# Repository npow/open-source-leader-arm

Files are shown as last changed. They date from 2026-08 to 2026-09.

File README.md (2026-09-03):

# Open-source Leader Arm

Open-source, low-cost, 3D-printed leader arm for teleoperating an SO-ARM

> **YAM prototype:** The `yam-encoder-leader` branch includes a no-solder,
> eight-piece, bearing-supported potentiometer leader for the six-axis I2RT
> YAM. A recorded two-leader cart was $32.34 before tax and import charges. See the
> [complete linked BOM, print list, assembly order, and validation limits](yam/README.md).

https://github.com/user-attachments/assets/977a0b56-c7d2-4a90-b86a-445dd3963871

A leader arm is moved by an operator to teleoperate a follower robot arm. A leader arm's joints are never driven, they simply report their joint angles, which the follower mirrors. So instead of using expensive servos, a cheap magnetic encoder like the AS5600 can be used. It results in an arm which is lighter to move by hand and is much cheaper than the one built with servos. 

Currently, the leader arm is tested against a simulated SO-ARM in MuJoCo with live physics, so you can pick up and move objects in the scene without a physical follower arm.

## Bill of materials

|Component| Quantity | Price|
|-|-|-|
|AS5600 encoder + Diametric magnet | 6 | 6 x 186 INR = 1,116 INR (~11.7 USD)|
|608 Bearing | 6 | 6 x 30 INR = 180 INR (~1.9 USD)|
| CJMCU TCA9548A I2C 8 Channel Multiplexer| 1 | 59 INR (~0.6 USD)|
|ESP32 | 1 | 550 INR (~5.8 USD)|
|28 AWG Silicon Wires | ~5m per color (4 colors) | 477 INR (~ 5 USD)|
|M3x10mm screws | 60 | 195 INR (~2 USD)|
|7x9cm Perfboard | 1 | 42 INR (~0.45 USD)|
| Rubber band | 1 | Negligible|
| |Total | 2,619 INR (~27.45 USD)|

Excluding the price of the 3D printed parts.

For context: the STS3215 servo used in the standard LeRobot leader arm costs around 24 USD each, and the leader arm needs six, roughly 144 USD in servos alone. Our entire component list comes in under 28 USD.

## How it works?
How it works explainer

**Why a mux?** - The AS5600 encoder has a fixed I2C address (0x36) and can't be changed. So we can't put more than one on a bus as they will all share the same address. The TCA9548A mux gives each encoder its own separate channel and connects one channel to the ESP32 at a time, so all six encoders can be read without any collision. 

## Wiring
wiring diagram

| TCA9548A | ESP32 | 
| --- | --- |
| VIN | 3V3 |
| GND | GND |
| SDA | D18 |
| SCL | D19 |
| RST | 3V3 |
| A0, A1, A2 | GND |

| AS5600 | ESP32 |
| --- | --- |
| VCC | 3V3 |
| GND, DIR | GND |

| AS5600 | TCA9548A |
|---|---|
| SDA | SDn |
| SCL | SCn |

n = the channel for that joint \
joint 0 → SD0/SC0, ... joint 5 → SD5/SC5

## Print Settings

Printed in PLA, 0.2mm layer height and 15% infill.

There are 19 unique parts and a total of 47 parts. All the parts are designed to not need support while printing. All the parts are already oriented for printing; if any part loads at an odd angle, lay its flat face on the bed. 

## Firmware

Flash firmware.ino to the ESP32 using the Arduino IDE: 

1. Install the ESP32 board support (Tools → Board → Boards Manager → search "esp32")
2. Open 'firmware/firmware.ino' and select your ESP32 board and port, and upload.
3. After uploading, open the serial monitor at **115200 baud rate** to check the output.

The firmware uses only the built-in 'Wire' library, so there's nothing else to install.

On boot it prints a channel scan. It prints "-1" if there is an issue with the connection, missing magnet or miswired encoder etc.,

If everything works then it prints "magnet ok"

Example : # ch0: AS5600 found, magnet ok, raw 1234

After the scan, it streams the six encoder readings as a comma-separated line, at 100 Hz.

## Running the software

The python side reads the encoder stream and drives a simulated SO-ARM in MuJoCo.

Install the dependencies and clone the robot model (the scripts expect it in the working directory)

```bash
pip install "mujoco>=3.2" pyserial
git clone https://github.com/google-deepmind/mujoco_menagerie.git
```

Then run one of the two scripts, passing your ESP32's port:

```bash
python teleop.py --port COM3              # plain teleop, empty scene
python teleop_sort_task.py --port COM3    # teleop + block sorting
```

On Linux, the port looks like '/dev/ttyUSB0'.

The script opens the simulated follower arm in its natural rest pose (hardcoded as the reference pose), so when the script starts, hold the leader arm in its reference pose and press ENTER. This makes sure that both the leader and the follower arm start with the same pose.

## Acknowledgements

This project builds on the work of several open-source projects:

- [SO-ARM100](https://github.com/TheRobotStudio/SO-ARM100) - the follower arm design this leader is built to teleoperate.
- [LeRobot](https://github.com/huggingface/lerobot) - the leader/follower teleoperation approach this project is based on.
- [MuJoCo Menagerie](https://github.com/google-deepmind/mujoco_menagerie) - the SO-ARM simulation model used by the teleop scripts.

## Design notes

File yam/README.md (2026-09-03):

# Simple no-solder YAM leader

A passive seven-axis potentiometer controller for the I2RT YAM. Each leader uses
seven factory-wired B10K rotary potentiometers, seven 6000-2RS bearings, an
Arduino Nano with soldered headers, a Nano I/O shield, and eight printed PETG
parts. The shopping list covers two leaders.

This is a first-print prototype, not qualified hardware. The tests check nominal
CAD geometry, motion sweeps, and a cable-length model. They do not prove printer
fit, strength, or a collision-free workspace. Print and pull-test the coupon
before committing to a full arm.

## A YAM at 0.68 scale

Teleoperation here is joint-space: each leader angle goes straight to the
matching follower joint. Your hand tracks the follower's gripper only if every
segment carries the same scale factor, so the chain is generated from
[`yam.urdf`](https://github.com/i2rt-robotics/i2rt/blob/main/i2rt/robot_models/arm/yam/v1/yam.urdf)
instead of being drawn to fit a print bed.

| Segment | YAM | Leader |
| --- | ---: | ---: |
| Base to J1 | 68.0 mm | 46.2 mm |
| J1 to J2 (shoulder offset) | 60.2 mm | 40.9 mm |
| J2 to J3 (upper arm) | 272.8 mm | 185.5 mm |
| J3 to J4 (forearm) | 261.5 mm | 177.8 mm |
| J4 to J5 | 90.9 mm | 61.8 mm |
| J5 to J6 | 53.9 mm | 36.7 mm |

The follower's lateral shoulder and elbow offsets are reproduced, so the forearm
folds past the upper arm the way the real arm's does. Assembled, the leader
reaches 321 mm forward and stands 326 mm tall.

It will not go much smaller. A GELLO joint is a 24 mm servo; a joint here is a
26 mm bearing plus a 17 mm potentiometer needing 35 mm of shaft and cradle behind
it. YAM's J5-to-J6 offset is 53.9 mm, or 36.7 mm at this scale, and the wrist
fits only because J5's sensor faces away from it and link 5 reaches J6's bearing
from behind. Below 0.66 the folded forearm hits the base plate. Smaller needs a
9 mm pot on a smaller bearing, or AS5600 encoders.

Two dimensions are not scaled, neither of them a mapped joint: the gripper lever
pivots 72 mm from the wrist roll axis because J6's potentiometer occupies the
first 35 mm of that direction, and the base plate, pedestal, and controller tray
are sized for the parts they hold.

`LEADER_SCALE` in `simple_cad/build_simple_leader.py` sets the size, and
`test_leader_is_a_uniformly_scaled_yam` fails if any segment drifts off it.

## Buy this for two leaders

Put the stated quantity in the cart. Quantities cover both leaders together.
Prices and links checked September 3, 2026.

| Buy this item | Cart quantity | Select exactly this option |
| --- | ---: | --- |
| [TZT WH148 factory-wired potentiometer](https://www.alibaba.com/product-detail/TZT-WH148-Potentiometer-B10K-B100K-Speed_1600768301952.html) | **14** | `B10K`, linear taper, 15 mm shaft, XH2.54 three-pin lead |
| [6000-2RS bearing](https://www.alibaba.com/product-detail/10x26x8-mm-ABEC-7-6000-2rs_1600053563089.html) | **20** | `10×26×8 mm`, sealed `6000-2RS`; fourteen used, six spare |
| [TZT ATmega328P/CH340 Nano V3.0](https://www.alibaba.com/product-detail/TZT-Type-C-USB-Nano-3_1600566932166.html) | **2** | `328P-Welded-TYPE-C USB`; both long header rows already soldered |
| [TZT Nano I/O sensor shield](https://www.alibaba.com/product-detail/TZT-NANO-V3-0-Adapter-Prototype_1601021706384.html) | **2** | Assembled red 58×54 mm board, two Nano socket rows, S/V/G headers |
| [30 cm male-to-female Dupont ribbon, 40 wires](https://www.alibaba.com/product-detail/30cm-40pin-M-to-F-Color_1601699032813.html) | **3** | `30cm`, `M to F`, `40P` |

Three ribbons, because a `40P` ribbon is forty separate one-conductor jumpers
joined side by side, not forty three-wire cables. One leader uses 13 three-wire
segments, or 39 wires, so two leaders use 78. Two ribbons give 80, which covers
that only if the delivered pigtails are 176 mm or longer, and the listing does
not state the length. At 160 mm the arm needs 84. Three ribbons give 120 and
cover leads down to 100 mm.

Expect roughly $33 before tax and import charges: about $18 of items and $26 of
shipping, less roughly $12 in discounts. With
[8.625% San Francisco sales tax](https://www.cdtfa.ca.gov/taxes-and-fees/rates.aspx)
that is about $36. Alibaba shows the exact shipping discount and import charge
only at checkout, so use the final charged total.

Also have a 1 kg spool of PETG, two USB-C data cables, and either eight #8 (about
4 mm) wood screws or two table clamps. Keep cable ties or electrical tape for
strain relief. Solid volume is 313 cm³ per leader, so slice the plate before
ordering only one spool.

## Print

Download this branch as a [ZIP](https://github.com/npow/open-source-leader-arm/archive/refs/heads/yam-encoder-leader.zip)
and use only `yam/simple_cad/generated/stl`. Do not use `cad_files/stl`; those
belong to the upstream SO-ARM design.

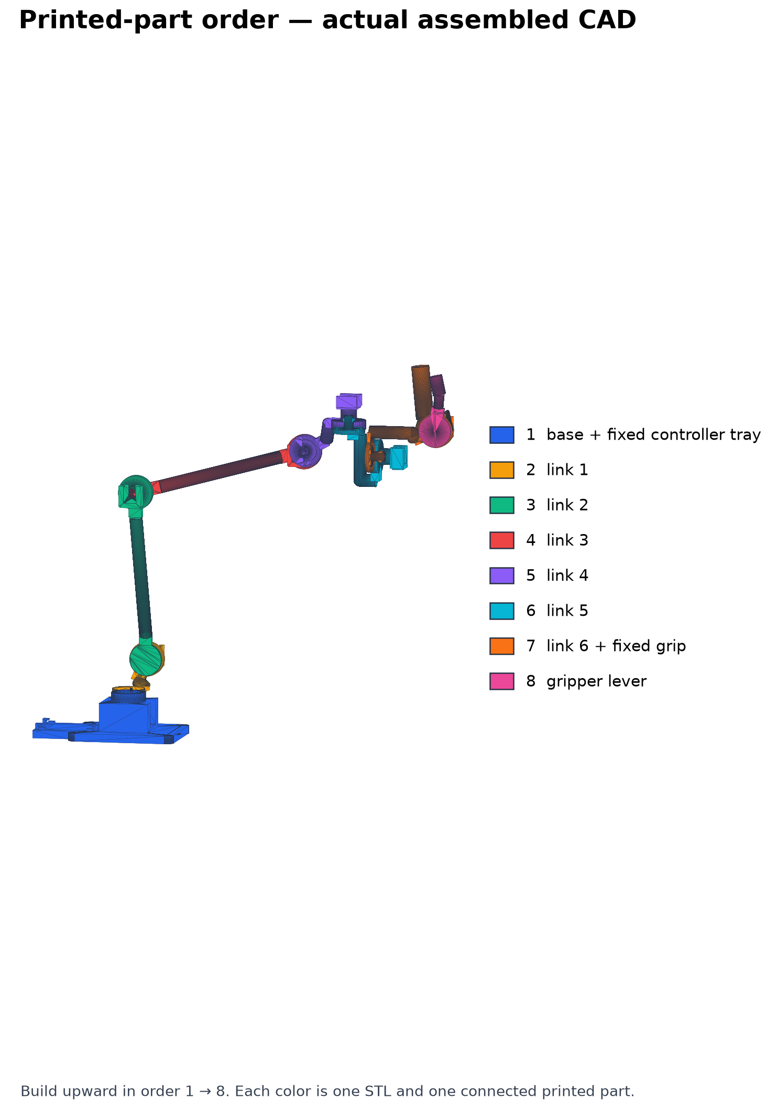
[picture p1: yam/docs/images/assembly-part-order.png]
The eight printed parts in assembly order


Print one [`joint_fit_test.stl`](simple_cad/generated/stl/joint_fit_test.stl)
first. It is a disposable coupon for the bearing pocket, snap axle, split shaft
socket, and pot cradle. Seat a bearing, snap the two pieces together, install a
pot, and pull firmly. Both snap shoulders must stay behind the bearing's inner
race and the printed wall must not crack.

One leader uses one copy of each file. Print two copies of every file for two
leaders:

1. [`simple_base.stl`](simple_cad/generated/stl/simple_base.stl), including the fixed controller tray
2. [`simple_link_1.stl`](simple_cad/generated/stl/simple_link_1.stl)
3. [`simple_link_2.stl`](simple_cad/generated/stl/simple_link_2.stl)
4. [`simple_link_3.stl`](simple_cad/generated/stl/simple_link_3.stl)
5. [`simple_link_4.stl`](simple_cad/generated/stl/simple_link_4.stl)
6. [`simple_link_5.stl`](simple_cad/generated/stl/simple_link_5.stl)
7. [`simple_link_6.stl`](simple_cad/generated/stl/simple_link_6.stl), including the fixed gripper jaw
8. [`simple_gripper_lever.stl`](simple_cad/generated/stl/simple_gripper_lever.stl)

PETG, 0.20 mm layers, five walls, six top/bottom layers, 25% gyroid. Enable
organic or tree supports from the build plate where needed, and about 0.20 mm
elephant-foot compensation. **Do not scale the STL.** The proportions are what
make the arm steer like the follower, and a scaled axle will not carry load. If
the coupon fit is wrong, tune the clearances in
[`simple_cad/README.md`](simple_cad/README.md) and regenerate.

Check your bed against the long parts:

| Part | Footprint as exported |
| --- | --- |
| `simple_link_2` (upper arm) | 35 × 214 mm |
| `simple_link_3` (forearm) | 201 × 75 mm |
| `simple_base` | 149 × 90 mm |

Everything else is under 110 mm. A 220 mm bed takes every part square on; a
180 mm bed takes the two long links only on the diagonal. `simple_link_2` exports
standing 95 mm tall on a 35 mm footprint, so it slices into a lot of support.
Re-orient it if you prefer, but keep the joint faces off the bed.

Editable STEP files are in `simple_cad/generated/step`.

## Assemble one leader

Repeat for the second leader.

### 1. Join the eight printed parts

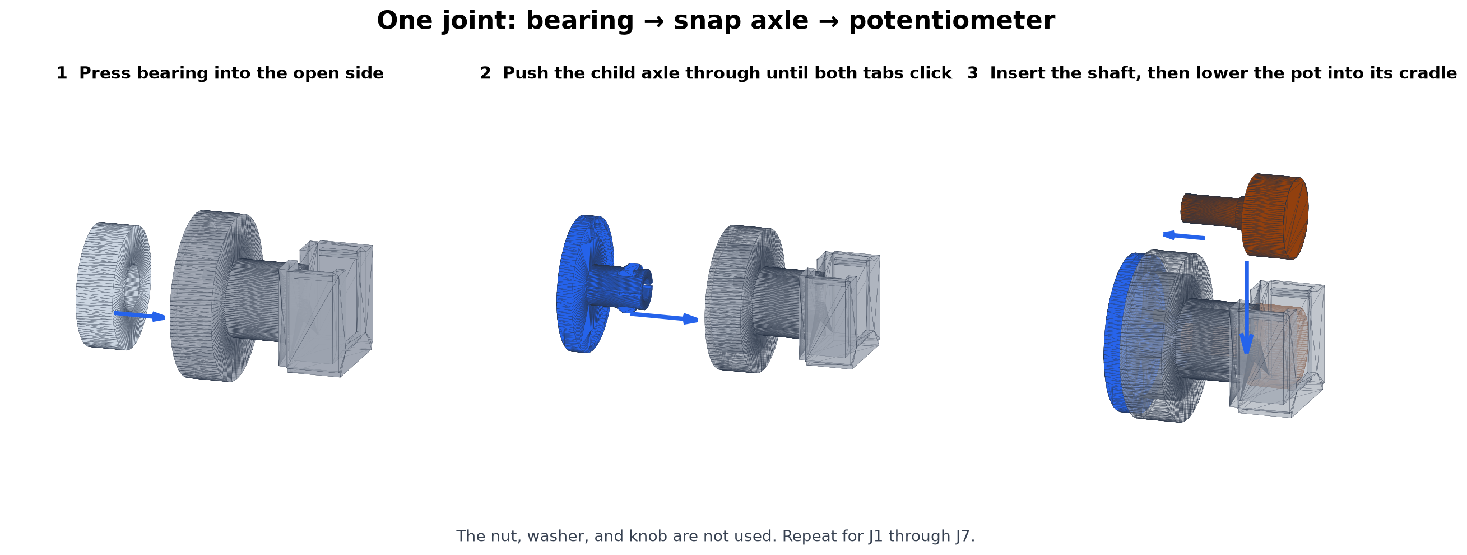
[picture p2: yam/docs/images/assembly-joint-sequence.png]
How a bearing, child axle, and potentiometer form one joint


1. Press one 6000-2RS bearing fully into the open round socket on the base and on
   links 1 through 6. Push only on the bearing's outer metal race.
2. Push link 1's axle straight through the base bearing until both printed
   shoulders click behind the inner race.
3. Continue in order: base, link 1, link 2, link 3, link 4, link 5, link 6,
   gripper lever.
4. Check that every joint turns freely and that pulling a child away from its
   bearing does not release the snap shoulders.

The bearing and printed flange carry the load. The potentiometer measures the
angle; it is not the axle. No screws or glue belong in a joint.

### 2. Center and install the seven pots

The printed stops are asymmetric, because each one is the follower joint's own
limit seen from the build pose. Center each pot on the middle of its printed
travel, then set the host offsets from
[the table below](#run-the-follower-software).

One joint at a time:

1. Swing the joint gently to each stop and leave it halfway between. Leave the
   gripper fully open for its zero position.
2. Connect the loose pot to the electronics and turn its shaft until the raw
   reading is about `512`.
3. **Unplug USB.** Push the shaft into the split socket, then lower the pot body
   and threaded bushing into the U-shaped cradle.
4. Do not install the pot's nut, washer, or knob.
5. Reconnect USB and move that joint slowly to both stops. The raw reading should
   stay between about `20` and `1000`, and the pot body must not twist.

### 3. Install the Nano shield and Nano

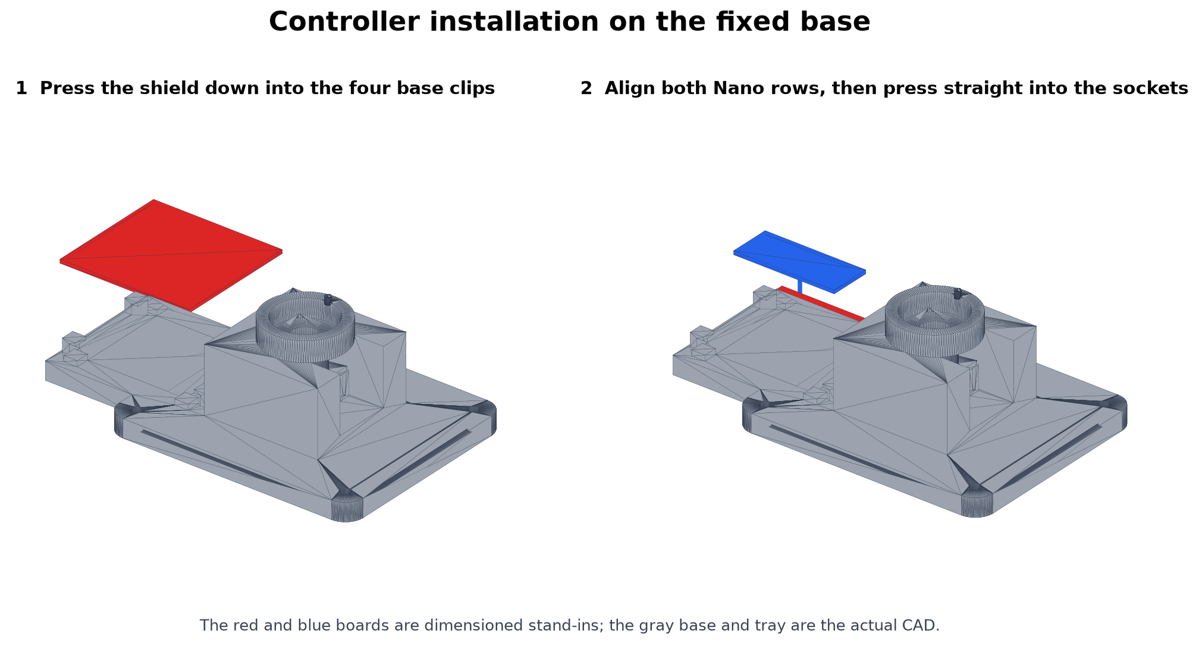
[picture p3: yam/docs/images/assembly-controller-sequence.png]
How the shield and Nano fit the fixed tray on the base


1. Rotate the red 58×54 mm shield so the Nano's USB connector faces outward, away
   from the J1 pedestal, then press it flat into the four clips on the base.
2. Match the labels on the Nano to the labels beside the shield sockets, `VIN` to
   `VIN` and `GND` to `GND`. USB-connector direction alone is not reliable.
3. Check every pin is over a socket, with no one-pin or one-row offset, then
   press both header rows down evenly. A shifted or reversed Nano can be
   destroyed when powered.

### 4. Secure the base

Clamp the base to the table, or use its four mounting holes and four #8 (about
4 mm) wood screws. Secure it before moving the arm through its range.

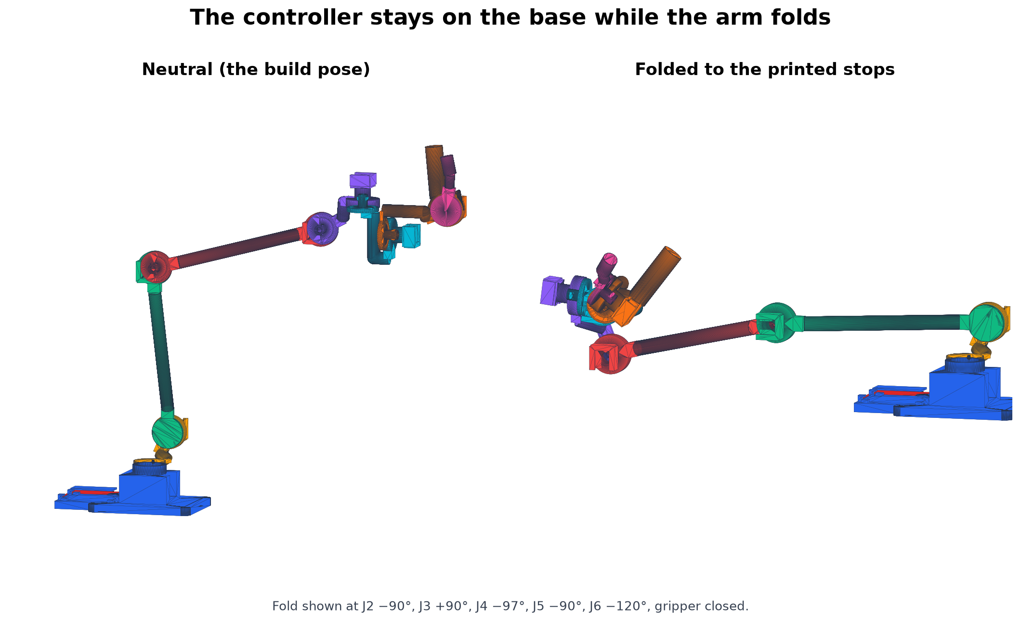
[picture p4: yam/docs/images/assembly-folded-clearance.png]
Neutral and fully folded poses with the controller fixed on the base


Before routing wires permanently, move slowly into the pictured fold, which puts
five joints on their stops at once: J2 −90°, J3 +90°, J4 −97°, J5 −90°, J6 −120°,
gripper closed. Stop rather than force the arm if a part, board, or cable
catches.

One combination is out of bounds. With the shoulder past J2 +20°, keep the elbow
above J3 −60° or the wrist comes down onto the base plate. A printed stop limits
one joint at a time, so this pair is an operating limit rather than a hardware
one.

The snap axles are serviceable but not meant for repeated disassembly. To remove
one, take out the pot, squeeze both axle shoulders inward through the cradle
opening, support the bearing, and pull the child straight out.

## Wire one leader

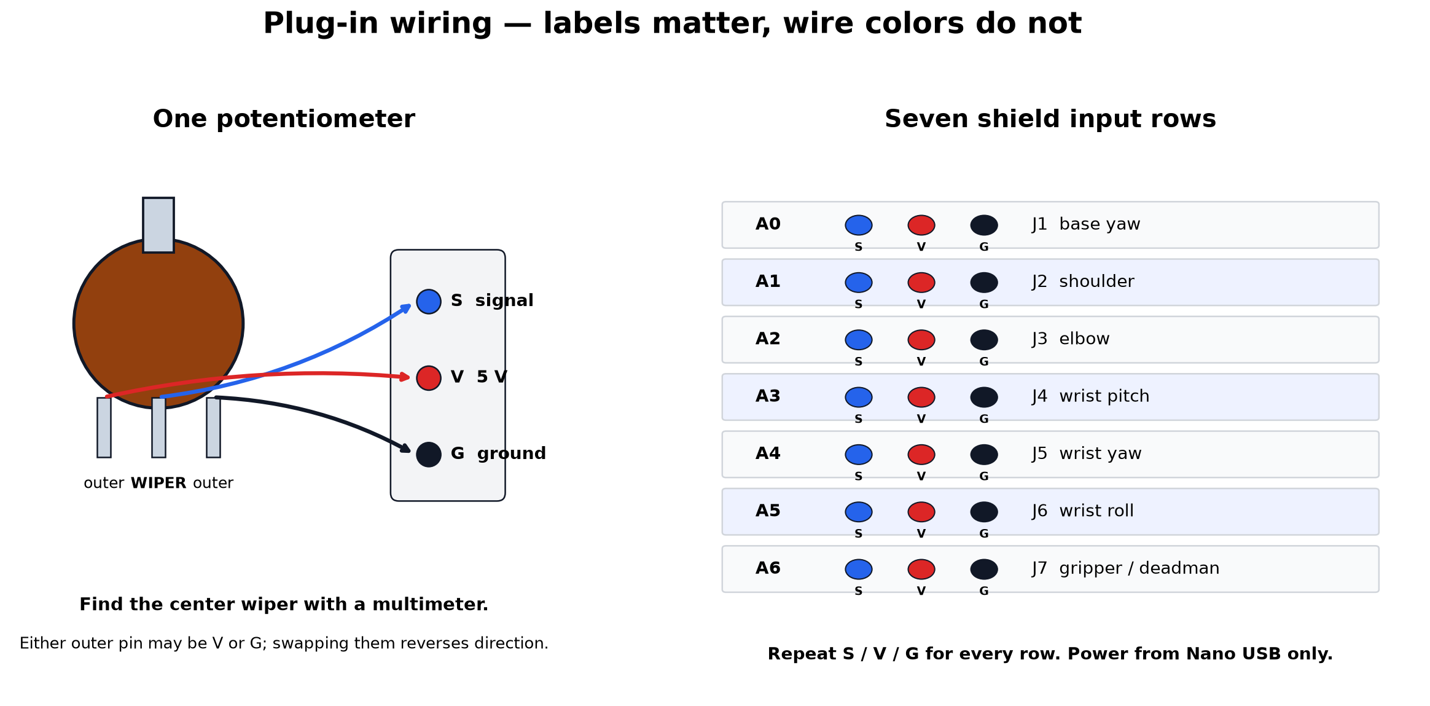
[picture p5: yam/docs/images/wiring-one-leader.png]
Potentiometer S/V/G wiring and the seven Nano-shield inputs


| Shield | Joint |
| ---: | --- |
| A0 | J1 base yaw |
| A1 | J2 shoulder |
| A2 | J3 elbow |
| A3 | J4 wrist pitch |
| A4 | J5 wrist yaw |
| A5 | J6 wrist roll |
| A6 | Gripper/deadman |

### Check every three-wire connector before power

Marketplace wire colors and pin order are not trustworthy. With the pot unpowered
and disconnected, meter its pins: the two outer terminals stay near 10 kΩ apart,
while the center wiper to either outer terminal changes as the shaft turns.
Connect:

- wiper to `S` (signal)
- either outer terminal to `V` (5 V)
- the other outer terminal to `G` (ground)

Swapping the two outer wires only reverses direction. Putting 5 V or ground on
the wiper is wrong. Confirm the XH-style plug or male jumper pins make firm
contact, and never force a housing that does not mate.

Power the Nano and the seven low-current pots from USB only. Do not connect the
shield's barrel jack or an external servo supply.

### Jumper wires per leader

The seller does not specify the factory lead length. The CAD assumes 200 mm, so
measure the delivered pots. At 200 mm, one leader needs:

| Channel | Segments | Wires |
| --- | ---: | ---: |
| J1 | 0 (reaches directly) | 0 |
| J2 | 1 | 3 |
| J3 | 1 | 3 |
| J4 | 2 | 6 |
| J5 | 3 | 9 |
| J6 | 3 | 9 |
| J7 | 3 | 9 |
| Total | 13 | 39 |

A segment is three loose jumpers, one each for S, V, and G, not a three-wire
cable. Peel groups of three off the ribbon and join male to female where a
channel needs more than one. Two leaders use 78 of the 120 wires in three
ribbons.

Leave a loose loop at every moving joint; a taut wire acts like a spring and
distorts the reading. Put junctions on straight link sections, not inside a
bending loop, and secure each one so normal motion cannot pull it apart.

<details>
<summary>CAD cable-length calculation</summary>

| Channel | Centerline route | Moving joints crossed | Total lead needed | 30 cm segments at 200 mm |
| --- | ---: | ---: | ---: | ---: |
| J1 | 61 mm | 0 | 96 mm | 0 |
| J2 | 137 mm | 1 | 226 mm | 1 |
| J3 | 308 mm | 2 | 475 mm | 1 |
| J4 | 468 mm | 3 | 710 mm | 2 |
| J5 | 558 mm | 4 | 857 mm | 3 |
| J6 | 601 mm | 5 | 946 mm | 3 |
| J7 | 653 mm | 6 | 1046 mm | 3 |

The route follows each intervening joint rather than cutting through space, then
adds 25% routing allowance, a 35 mm service loop per moving joint crossed, and
20 mm for connectors and strain relief.

</details>

## Flash and test the controller

Upload
[`firmware/yam_encoder_leader/yam_encoder_leader.ino`](../firmware/yam_encoder_leader/yam_encoder_leader.ino)
in the Arduino IDE:

1. Select Arduino Nano, the correct port, and ATmega328P. If a clone will not
   upload, try ATmega328P (Old Bootloader).
2. Keep the gripper fully released while plugging in USB or resetting. The
   firmware averages that position as the deadman-off baseline.
3. Open Serial Monitor at 115200 baud. It should emit `YAMP1` frames at 100 Hz,
   every raw channel within `[4, 1019]`.
4. Move one joint at a time, confirm the expected channel changes smoothly, then
   pull lightly on its cable and recheck.

The firmware averages four ADC reads per sample. A reading at an ADC endpoint
disables the deadman, but that is a limited wiring check, since an open analog
input can float to a valid-looking value. Squeezing the gripper by about 25
counts sets the protocol's deadman bit. In the hardware host configuration,
releasing it holds the follower at its current measured pose; the simulation
configuration ignores it by default. This is not a safety-rated emergency stop.

## Run the follower software

Use the matching `yam-encoder-leader` branch of
[`npow/gello_software`](https://github.com/npow/gello_software/tree/yam-encoder-leader).
Edit the Nano port in `configs/yam_encoder_sim.yaml`, hold the arm in its neutral
pose with the gripper open, and test one leader in simulation first:

```bash
python experiments/launch_yaml.py \
  --left-config-path configs/yam_encoder_sim.yaml
```

**Those configs do not match this arm out of the box, and this branch does not
change them.** Set each joint's offset so a centered pot reads the follower angle
below, and set `joint_signs` to −1 where shown:

| Joint | Follower angle at a centered pot | `joint_signs` |
| --- | ---: | ---: |
| J1 base yaw | 0° | −1 |
| J2 shoulder | 105° | +1 |
| J3 elbow | 98° | +1 |
| J4 wrist pitch | −3.5° | +1 |
| J5 wrist yaw | 0° | −1 |
| J6 wrist roll | 0° | +1 |

J1 and J5 take −1 because their potentiometers face the other way, which gives
the pedestal and the wrist their clearance. Every axis is one degree of leader
per degree of follower, with no per-joint gain. If a joint still moves backward,
fix it in `joint_signs`; do not swap wires while powered. Use
`configs/yam_encoder_hw.yaml` only after directions, limits, disconnect behavior,
rate limits, and the gripper deadman all work in simulation.

For two leaders, copy the config for the right side with the second Nano's serial
port and the right follower's robot or CAN endpoint, then add
`--right-config-path`. Never point both sides at the same device.

### What the leader cannot reach

Every printed stop is the follower joint's own limit, with two exceptions:

| Joint | Follower travel | Leader travel | Given up |
| --- | --- | --- | --- |
| J1 base yaw | −150° to +180° | ±140° | 40° one way, 10° the other |
| J3 elbow | 0° to 180° | 16° to 180° | 16° at the folded end |

J1 needs 330°, more than one 300° potentiometer can measure, so its stops sit
symmetrically inside what the pot reads. J3 stops short because the printed
forearm, fatter than the real arm's, reaches the upper arm over the last 16° of
its fold.

## Known prototype limitations

- Print and pull-test the coupon. FDM fit and snap strength vary by printer,
  PETG, cooling, and layer adhesion. This design has no certified load rating.
- Every joint clears its full printed-stop range with the whole distal chain
  attached, and the shoulder and elbow are swept as a grid. That does not prove
  every multi-joint combination is free of self-collision, so move slowly and
  never force a fold.
- A faithfully scaled YAM inherits the follower's own folded self-collisions. A
  URDF joint limit is not a promise of a collision-free workspace, on either arm.
- Collision tests use a conservative 78×74×22 mm envelope for the shield, Nano,
  headers, and plugs. Real parts and flexible wire paths still need physical
  inspection.
- WH148 carbon potentiometers are inexpensive wear parts, not precision encoders.
  Verify linearity, backlash, electrical travel, and connector grip.
- This is prototype hand-input equipment, not a payload support or a safety-rated
  control device.

CAD source, regeneration instructions, and geometry tests are in
[`simple_cad`](simple_cad/README.md).

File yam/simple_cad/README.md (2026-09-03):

# Parametric simple YAM leader CAD

[`build_simple_leader.py`](build_simple_leader.py) is the source of truth for
the eight-piece, bearing-supported potentiometer leader. Dimensions are
millimetres. Generated editable STEP and print-oriented STL files are under
[`generated`](generated).

## The chain comes from the follower

`YAM_URDF_CHAIN` holds the joint origins, axes, and limits copied out of
`i2rt/robot_models/arm/yam/v1/yam.urdf`. `yam_chain()` runs forward kinematics
over those rows at `YAM_BUILD_POSE_DEG` and multiplies by `LEADER_SCALE`, which
is the single number that sets the arm's size. `JOINTS` and `JOINT_LIMITS_DEG`
are derived from that and must not be hand-edited.

Joint-space teleoperation only tracks the follower if the leader is a *uniform*
scaling of it, so `test_leader_is_a_uniformly_scaled_yam` compares every segment
against the URDF at both 1.0 and `LEADER_SCALE`. Per-segment adjustment is the
failure this guards against: it leaves every angle legal and silently removes
the correspondence the operator steers by.

`YAM_BUILD_POSE_DEG` uses multiples of 90 degrees so every axis lands on a world
axis, which is all `_orient_x` can build, and it sits near the middle of every
follower joint range. Printed stops then follow as `follower limit - build
angle`, clipped by `POT_USABLE_TRAVEL_DEG` and `SELF_COLLISION_LIMIT_DEG`.
`follower_travel_lost_deg()` reports everything the leader gives up.

`POT_MOUNT_SIGN` flips J1, J5, and J7. The socket and its potentiometer always
extend along +axis, so the sign picks which side of a joint the sensor sticks
out of, and each flip costs a `joint_signs` of −1 in the host config. J1 faces
down so its pedestal is a column under the socket instead of a wedge threaded
through link 1's sweep; J5 faces up so link 5 has a corridor down to J6.

### How small can it go?

What this suite reports at other scales:

| Scale | Result |
| ---: | --- |
| 0.75 | passes |
| 0.70 | collisions all clear, but `simple_link_5` is not a valid single solid |
| 0.68 | passes; shipped |
| 0.67 | passes |
| 0.66 | the folded forearm reaches the base plate |

0.66 is the first real collision, so 0.68 keeps a step of margin. Below that the
base plate and Nano shield stop shrinking with the arm, and then the joints
themselves run out of room.

The model is not valid at every scale in between. `simple_link_5` fails the
valid-solid check at 0.70 and 0.74 while passing at 0.68 and 0.75. The cause is
near-tangency rather than packing: at those spacings the descent beam leaves J5
on a short radial neck that puts its surface about a millimetre from the snap
axle and straddling `STOP_GROOVE_OUTER_RADIUS`, so the union drops a segment
instead of fusing it. If you change `LEADER_SCALE`, run the suite. If link 5
fails, route it out of J5 along the joint axis first, where nothing is nearby,
instead of on that neck.

## Generate and test

```bash
python -m venv .venv-cad
. .venv-cad/bin/activate
pip install -r yam/simple_cad/requirements.txt
python yam/simple_cad/build_simple_leader.py
python yam/simple_cad/render_assembly_guides.py
PYTHONPATH=yam/simple_cad pytest -q yam/simple_cad/test_simple_leader.py
```

The renderer creates the five README figures in `yam/docs/images` from the
same printed-part geometry. Purchased bearings, pots, and boards are shown as
dimensioned stand-ins rather than scanned manufacturer models.

Generation refuses to export unless all eight final parts are connected valid
solids, adjacent rigid parts do not interfere in the assembly zero pose, and
every potentiometer channel fits the documented cable budget.

The test suite moves each joint individually across its complete printed-stop
travel with the entire distal chain attached. It checks every pair of the eight
parts rather than only neighbours, and it includes the fixed controller's
78×74×22 mm electronics envelope.

Additional regressions cover all 27 nominal J4/J5/J6 corner combinations,
shoulder folds across five J1 yaw samples, a wrist-over-tray pose, a six-joint
fold onto the printed stops across the yaw range, and a shoulder/elbow grid that
checks the fold envelope in both directions: everything inside it clears, and the
corner it excludes does collide. They do not exhaustively sample continuous
multi-joint space or prove a self-collision-free workspace.

The gripper's leaf/post overlap is excluded from the pair checks and tested on
its own, because that overlap is the intended elastic spring engagement.

These checks do not replace a physical fit test. FDM holes and snap features
vary with printer, material, layer direction, cooling, and marketplace parts.

## Printer fit constants

Print [`generated/stl/joint_fit_test.stl`](generated/stl/joint_fit_test.stl)
before the full arm. Tune only the compensated values below; do not change the
purchased-component dimensions or scale the STL in a slicer.

| Constant | Default | Meaning |
| --- | ---: | --- |
| `BEARING_POCKET_DIAMETER` | 26.20 | Modeled hole for the 26 mm 6000-2RS outer race |
| `BEARING_POCKET_DEPTH` | 8.15 | Modeled depth for the 8 mm bearing |
| `AXLE_DIAMETER` | 9.80 | Running fit in the 10 mm inner race |
| `POT_BODY_CLEARANCE` | 0.45 | Added diameter around the nominal 17 mm WH148 body |
| `POT_BUSHING_CLEARANCE` | 0.35 | Added diameter around the nominal 7 mm threaded bushing |
| `POT_SHAFT_SOCKET_DIAMETER` | 5.85 | Interference fit inside the nominal 6 mm knurled shaft socket |
| `NANO_SHIELD_EDGE_CLEARANCE` | 0.60 | Clearance on the sourced 58×54 mm Nano I/O shield edges |

Change one fit at a time and regenerate the coupon. A loose bearing pocket or
cracked axle is a failed part, not something to repair with a load-bearing blob
of glue.

## Cable budget

The linked seller does not specify the potentiometer lead length. The model
uses a 200 mm assumption. The controller is fixed at the base, so distant
channels chain as many as four 300 mm male-to-female jumper segments. `cable_runs()`
computes each length and segment count; `validate_cable_reach` fails generation
if two leaders consume more individual conductors than the three 40-wire ribbons
in the BOM provide.

| Constant | Default | Meaning |
| --- | ---: | --- |
| `CONTROLLER_TRAY_CENTER` | derived | PCB centre, set behind the pedestal |
| `POT_LEAD_LENGTH` | 200 | Assumed factory lead; measure the delivered parts |
| `EXTENSION_LEAD_LENGTH` | 300 | Length of one M-to-F jumper segment |
| `JUMPER_PACK_COUNT` | 3 | Number of ribbons for two leaders |
| `JUMPER_PACK_WIRES` | 40 | Individual conductors per ribbon |
| `CABLE_ROUTING_FACTOR` | 1.25 | Additional routing slack over the joint-by-joint centerline path |
| `CABLE_SERVICE_LOOP` | 35 | Slack per rotating joint a run crosses |
| `CABLE_TERMINATION_ALLOWANCE` | 20 | Connector bodies and strain relief |

Under the 200 mm assumption, J1 reaches directly, J2 uses one segment, J3/J4 use
two, J5/J6 use three, and J7 uses four. That is 45 individual jumper wires per
leader and 90 for two, leaving 30 spares. Three ribbons still cover the arm at a
100 mm factory lead, so the budget does not depend on that unstated length.

## Fixed base and controller

J1's socket faces down, so `_pedestal` is a plain column carrying the whole
underside of that socket, open toward the arm so the potentiometer still slides
into its cradle after printing. Facing the socket up instead forces the pedestal
to reach through a gap in link 1's own sweep, and the follower's 33.9 mm shoulder
offset swings link 1 about 21 degrees wide in plan view, leaving no such gap at
J1's full travel. The governing section between the plate and the socket is over
1700 mm^2.

The horizontal Nano-shield sidecar is integral with the base, producing a
149×90 mm print footprint. Four risers leave clearance for solder joints on the
shield underside and four flexible clips retain its long edges. The PCB is
oriented with the Nano USB connector facing outwards, away from J1. The
controller and USB cable therefore remain stationary as every joint moves.

## Two links do not take the direct route

`_link` builds a link as a plug, a radial neck, a beam, and the next socket.
Two joints cannot use it:

- `build_link_5` reaches J6's socket from the sector opposite J5. J5 and the
  gripper are both on the same side of J6, and J6 rolls 240 degrees, so its
  moving link sweeps every radial direction but a 120 degree sector on the far
  side. A straight beam into that socket locks the wrist.
- `build_link_6` runs parallel to the roll axis until it is clear of J6's
  bearing seat and pot holder before turning toward the lever pivot.

Both use `_beam_path_pieces`, which puts a ball at each corner. Two cylinders
meeting exactly at a shared end plane are a tangency rather than a shared
volume, and the boolean will quietly drop one of them, leaving a link in two
pieces that happen to touch.

## Parametric limits

`JOINT_LIMITS_DEG` defines the printed pin-and-arc stops, and it is derived
rather than chosen: each stop is the follower's own limit seen from the build
pose. J1 is clipped to ±140° because its 330° of follower travel exceeds what
one potentiometer measures, and J3 is clipped to −74° because the printed
forearm reaches the upper arm before the follower's fold ends. Everything else
matches the follower exactly, so the host needs no per-joint gain.

`stop_limited_range` adds the groove clearance and subtracts the stop pin's own
half-width, giving what the printed stops really permit because the pin stops on
its edge rather than its centre. That, not the declared range, is what the
collision suite sweeps.

`COUPLED_FOLD_LIMIT_DEG` and `fold_is_permitted` record the one pair of joints a
single-joint stop cannot protect: shoulder forward past J2 +20° with the elbow
below J3 −60° puts the wrist on the base plate.

`test_j2_reaches_its_full_printed_stop_without_hitting_the_base` and
`test_controller_is_fixed_to_the_base_and_old_wrist_collision_is_clear` hold the
shoulder and the wrist clear of the base and the fixed tray; the fold-grid tests
cover the combinations between them.

If link positions, controller location, joint envelope, beam radius, or stop
ranges change, rerun the complete collision suite and regenerate every STEP and
STL. A successful boolean check proves only the modeled nominal geometry; it
does not model printer tolerance, cable sweeps, spring deformation, creep, or
fatigue.

## Prototype limitations

- PETG is required for the snap shoulders, split shaft coupling, pot clips,
  controller clips, and gripper flexure.
- The 6000 bearing carries the joint load in the model; the potentiometer shaft
  is an unloaded angular coupling. The printed assembly has no certified load
  rating.
- The generated motion tests use rigid nominal parts. Check service loops and
  marketplace part variations across the complete real motion envelope.
- WH148 carbon potentiometers are low-cost wear parts with more backlash,
  nonlinearity, and finite life than magnetic encoders.
- Treat the full arm as prototype hand-input equipment, never as a payload
  support or safety-rated control device.

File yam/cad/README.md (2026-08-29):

# Parametric YAM Wrist Adapter

> **Legacy prototype:** These files belong to the earlier AS5600/M3-screw
> design and are not used by the current inexpensive leader. Start with the
> [current BOM, print list, and assembly guide](../README.md), and print only
> the STLs under `yam/simple_cad/generated/stl` for that build.

The YAM needs one more arm axis than the original SO-ARM leader. These files
insert a standard encoder cartridge at 90 degrees between the original wrist
and handle without changing the proven AS5600 housing, bearing housing, or
rotor.

## Parts

- `yam_wrist_axis_base` bolts to the output flange of the original wrist.
- `yam_wrist_axis_upright` slides into the two keyed base sockets and carries
  the added encoder/bearing cartridge.

The two legs leave a 12 mm central passage for the previous joint's rotor and
wiring. Four M3x16 screws clamp the upright to the base. Both cartridge faces
use the original 40 mm envelope and 31.05 mm four-hole pattern.

## Generate

Create an isolated Python environment and run:

```bash
pip install -r yam/cad/requirements.txt
python yam/cad/build_wrist_adapter.py
pytest -q yam/cad/test_wrist_adapter.py
```

The generator writes editable STEP files and print-oriented STL files under
`yam/cad/generated`. Dimensions are millimetres.

## Prototype print

Use PLA or PETG, 0.2 mm layers, four walls, and at least 25% infill. Both STLs
are exported on a flat face and should not require supports. Check the following
before assembling the arm:

1. An M3 screw passes through every 3.2 mm clearance hole.
2. The upright legs slide into the base sockets without forcing them. The
   modeled clearance is 0.3 mm; adjust `SOCKET_SLOT_X/Y` for the printer.
3. A standard encoder or bearing housing aligns with all four flange holes.
4. The previous rotor and cable bundle clear the 12 mm center passage through
   the full required rotation.

This is a first-print prototype. Perform those fit checks on the two adapter
pieces before printing the complete leader.

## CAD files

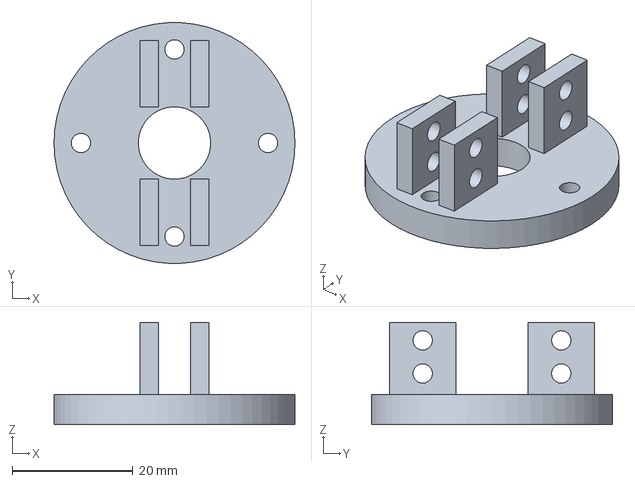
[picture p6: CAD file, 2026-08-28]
yam/cad/generated/step/yam_wrist_axis_base.step
40.0 x 39.9 x 17.0 mm

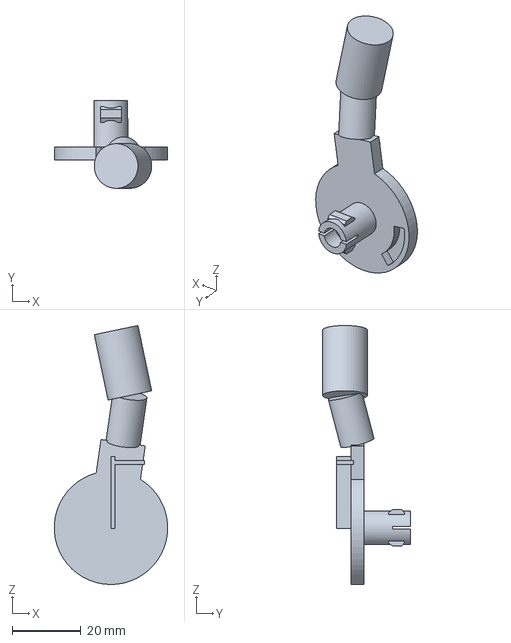
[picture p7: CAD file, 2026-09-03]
yam/simple_cad/generated/step/simple_gripper_lever.step
33.0 x 25.5 x 75.3 mm

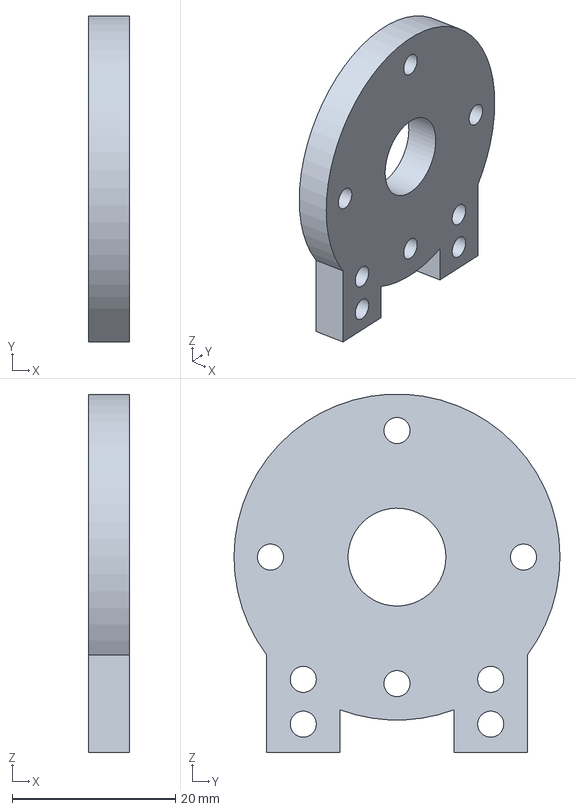
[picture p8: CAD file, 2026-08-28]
yam/cad/generated/step/yam_wrist_axis_upright.step
5.00 x 40.0 x 44.0 mm

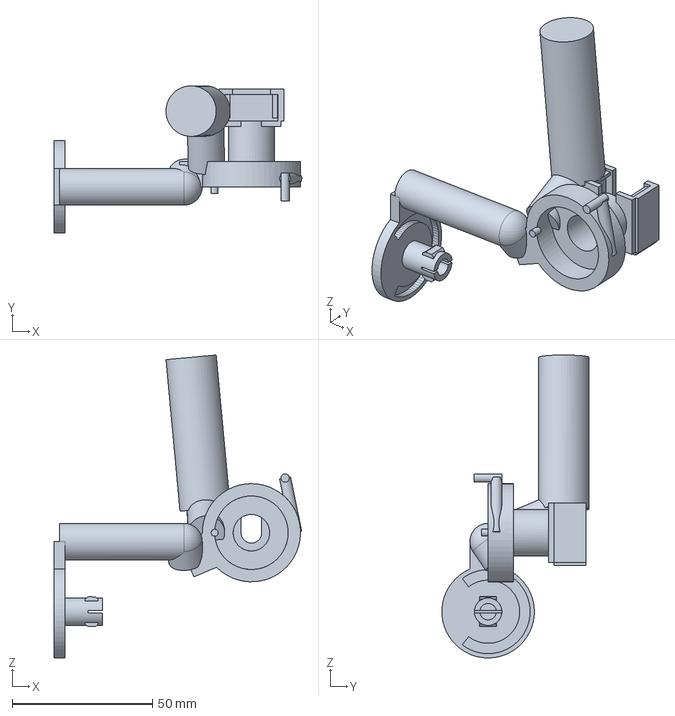
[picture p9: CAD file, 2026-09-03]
yam/simple_cad/generated/step/simple_link_6.step
88.2 x 52.5 x 108.0 mm

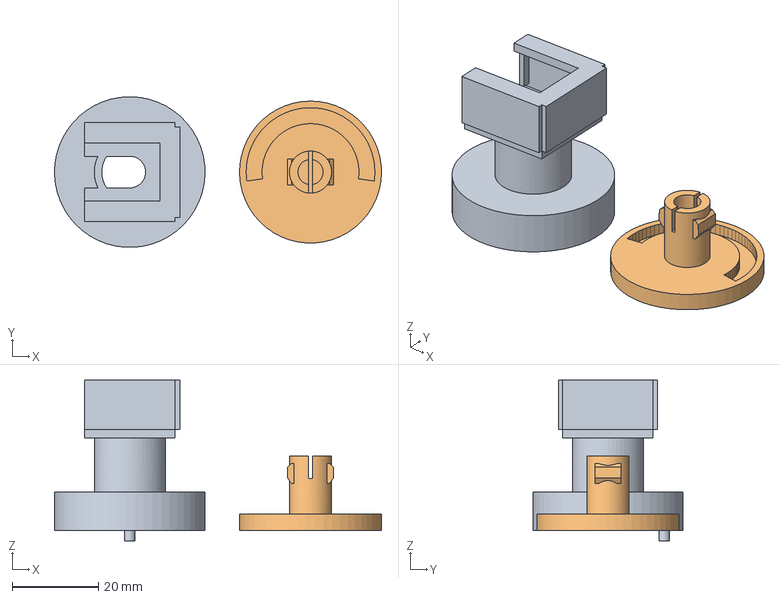
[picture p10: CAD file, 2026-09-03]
yam/simple_cad/generated/step/joint_fit_test.step
76.0 x 35.0 x 37.4 mm

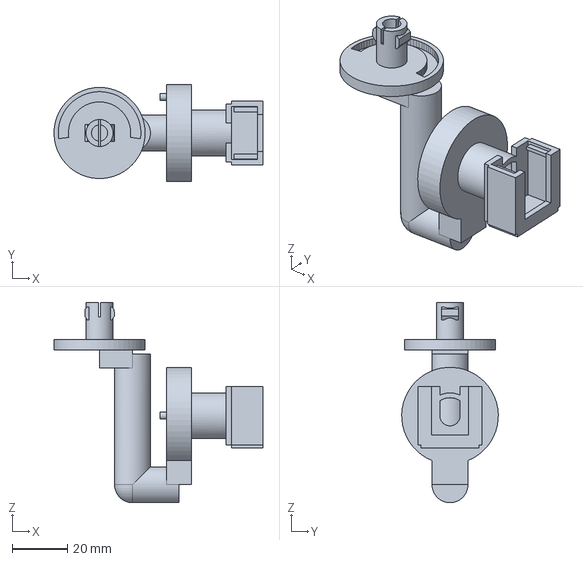
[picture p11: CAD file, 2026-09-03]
yam/simple_cad/generated/step/simple_link_5.step
75.7 x 35.0 x 72.5 mm

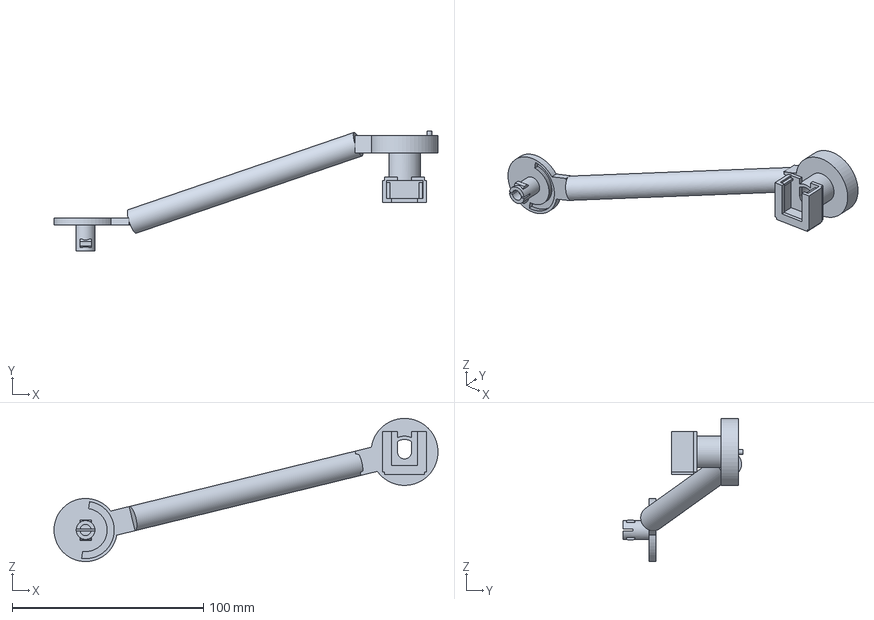
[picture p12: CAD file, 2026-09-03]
yam/simple_cad/generated/step/simple_link_3.step
200.6 x 62.7 x 74.8 mm

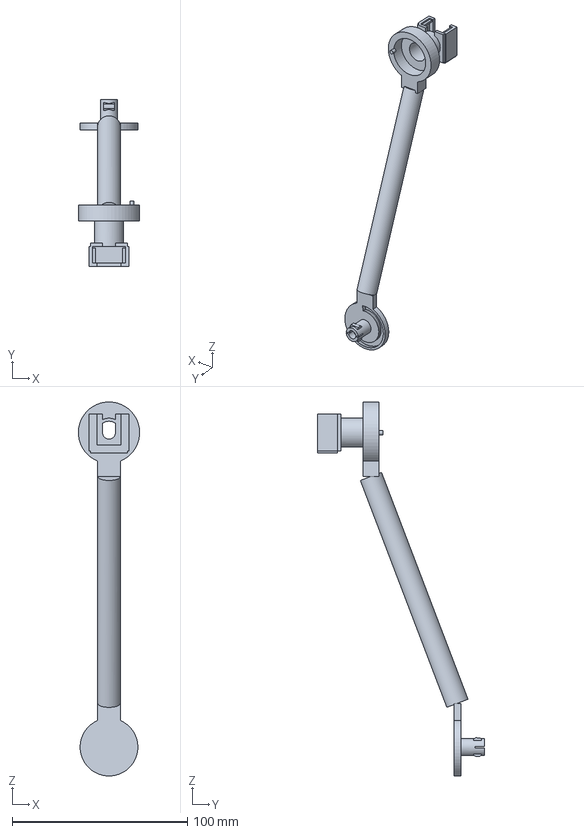
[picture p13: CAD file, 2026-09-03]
yam/simple_cad/generated/step/simple_link_2.step
35.0 x 95.2 x 213.5 mm

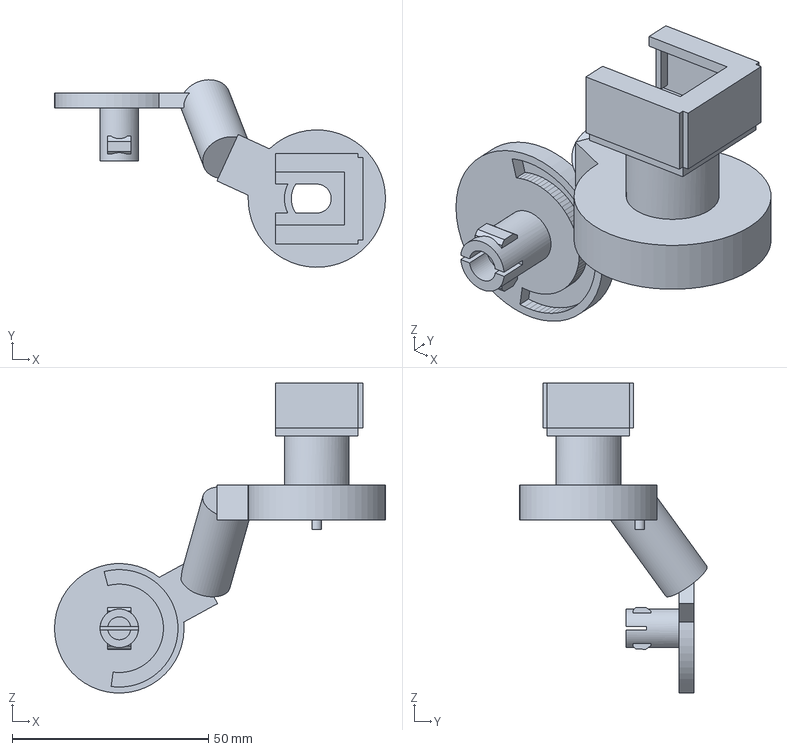
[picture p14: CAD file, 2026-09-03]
yam/simple_cad/generated/step/simple_link_4.step
84.3 x 47.8 x 79.0 mm

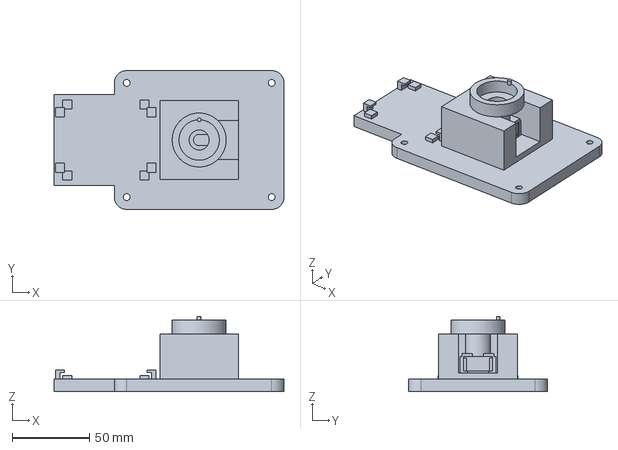
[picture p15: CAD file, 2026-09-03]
yam/simple_cad/generated/step/simple_base.step
149.1 x 90.0 x 48.6 mm

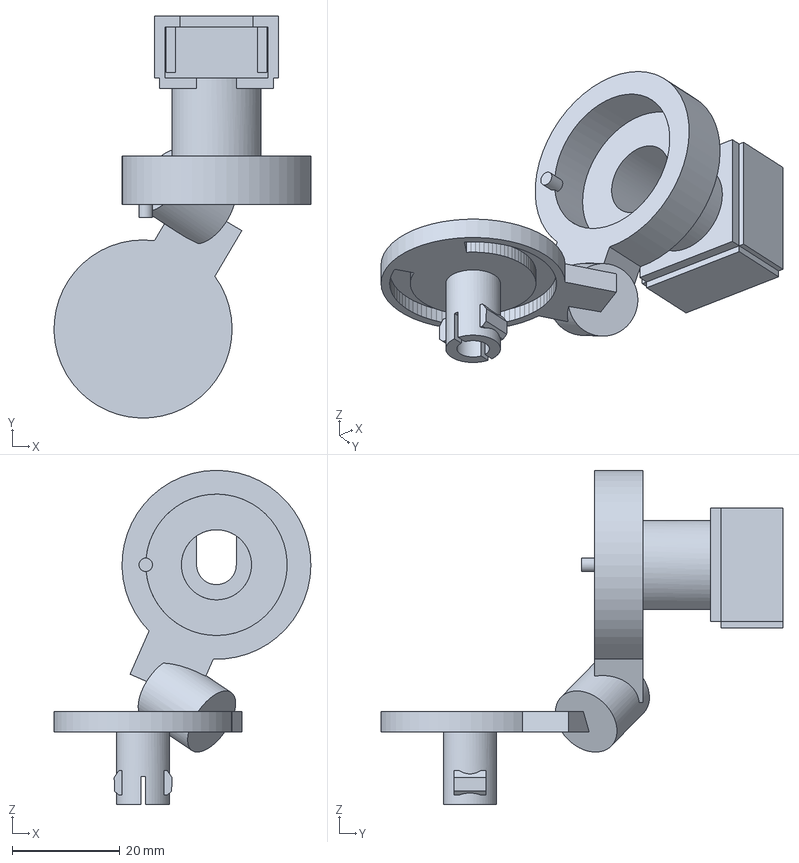
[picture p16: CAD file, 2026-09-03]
yam/simple_cad/generated/step/simple_link_1.step
47.6 x 74.5 x 61.9 mm

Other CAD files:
yam/cad/generated/stl/yam_wrist_axis_base.stl
yam/cad/generated/stl/yam_wrist_axis_upright.stl
yam/simple_cad/generated/stl/joint_fit_test.stl
yam/simple_cad/generated/stl/simple_base.stl
yam/simple_cad/generated/stl/simple_gripper_lever.stl
yam/simple_cad/generated/stl/simple_link_1.stl
yam/simple_cad/generated/stl/simple_link_2.stl
yam/simple_cad/generated/stl/simple_link_3.stl
yam/simple_cad/generated/stl/simple_link_4.stl
yam/simple_cad/generated/stl/simple_link_5.stl
yam/simple_cad/generated/stl/simple_link_6.stl

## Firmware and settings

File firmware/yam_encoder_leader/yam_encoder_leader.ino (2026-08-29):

// No-solder YAM leader: seven factory-wired B10K potentiometers on a Nano
// I/O sensor shield.  Compatible with the classic ATmega328P Arduino Nano.

#define N_CH 7
#define GRIPPER_CH 6
#define SAMPLE_HZ 100
#define ADC_MIN_VALID 3
#define ADC_MAX_VALID 1020
#define DEADMAN_COUNTS 25

const uint8_t POT_PINS[N_CH] = {A0, A1, A2, A3, A4, A5, A6};

static uint32_t sequenceNumber = 0;
static int16_t releasedGripper = 0;

int16_t readPot(uint8_t channel) {
  uint16_t total = 0;
  for (uint8_t sample = 0; sample < 4; sample++) {
    total += analogRead(POT_PINS[channel]);
  }
  const int16_t value = (total + 2) / 4;
  if (value <= ADC_MIN_VALID || value >= ADC_MAX_VALID) return -1;
  return value;
}

int16_t captureReleasedGripper() {
  uint32_t total = 0;
  uint8_t validSamples = 0;
  for (uint8_t sample = 0; sample < 64; sample++) {
    const int16_t value = readPot(GRIPPER_CH);
    if (value >= 0) {
      total += value;
      validSamples++;
    }
    delay(5);
  }
  return validSamples == 0 ? -1 : total / validSamples;
}

void diagnose() {
  Serial.println(F("# YAM seven-channel potentiometer scan"));
  for (uint8_t channel = 0; channel < N_CH; channel++) {
    Serial.print(F("# ch"));
    Serial.print(channel);
    Serial.print(F(": raw "));
    Serial.println(readPot(channel));
  }
  Serial.print(F("# released gripper baseline: "));
  Serial.println(releasedGripper);
  Serial.println(F("# squeeze gripper to enable commands"));
}

void setup() {
  Serial.begin(115200);
  analogReference(DEFAULT);
  delay(1200);
  // Keep the gripper fully released while the controller starts.  Its printed
  // flexure provides the return action, so no button or extra wire is needed.
  releasedGripper = captureReleasedGripper();
  diagnose();
}

void loop() {
  static uint32_t nextSampleMicros = 0;
  const uint32_t periodMicros = 1000000UL / SAMPLE_HZ;
  const uint32_t nowMicros = micros();
  if (static_cast<int32_t>(nowMicros - nextSampleMicros) < 0) return;
  nextSampleMicros += periodMicros;
  if (static_cast<int32_t>(nowMicros - nextSampleMicros) >= 0) {
    nextSampleMicros = nowMicros + periodMicros;
  }

  int16_t counts[N_CH];
  bool allValid = releasedGripper >= 0;
  for (uint8_t channel = 0; channel < N_CH; channel++) {
    counts[channel] = readPot(channel);
    if (counts[channel] < 0) allValid = false;
  }
  const bool gripperSqueezed =
      counts[GRIPPER_CH] >= 0 &&
      abs(counts[GRIPPER_CH] - releasedGripper) >= DEADMAN_COUNTS;

  // Versioned output lets the host reject controller reboots and stale data:
  // YAMP1,sequence,millis,count0,...,count6,deadman
  Serial.print(F("YAMP1,"));
  Serial.print(sequenceNumber++);
  Serial.print(',');
  Serial.print(millis());
  for (uint8_t channel = 0; channel < N_CH; channel++) {
    Serial.print(',');
    Serial.print(counts[channel]);
  }
  Serial.print(',');
  Serial.println(allValid && gripperSqueezed ? 1 : 0);
}

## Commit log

2026-08-28 Add seven-channel YAM encoder leader prototype
    [yam_wrist_axis_base.step, yam_wrist_axis_base.stl, yam_wrist_axis_upright.step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]
2026-08-28 Document complete YAM BOM and print set
2026-08-28 Clarify where to download the complete print set
2026-08-28 Add purchase links and budget pricing to YAM BOM
2026-08-28 Redesign YAM leader for simple no-solder assembly
    [joint_fit_test.step, joint_fit_test.stl, simple_base.step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]
2026-08-29 Build low-cost no-solder YAM potentiometer leader
    [joint_fit_test.step, joint_fit_test.stl, simple_base.step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]
2026-09-02 Fix base load path, check cable reach, sweep full chain for collisions
    Rebuild the base pedestal. The J1 socket met the two 6 mm columns only
    through a pair of small stub lenses, so the whole arm's bending load
    crossed ~122 mm^3 of section modulus in PETG, across the layer lines. A
    buttressed slab now reaches the socket wall through the wedge of azimuth
    link 1 never sweeps, derived from J1's permitted travel rather than
    guessed: 77 -> 471 mm^2 area and 122 -> 637 mm^3 section modulus at the
    governing band. Only simple_base changes shape; every other part is
    volumetrically identical, so an already-printed coupon stays valid.
    Model the cable budget instead of asserting it. The pots ship with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
    [joint_fit_test.step, joint_fit_test.stl, simple_base.step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]
2026-09-03 Document no-solder two-leader sourcing
2026-09-03 Rewrite assembly guide with CAD visuals
2026-09-03 Move leader controller to fixed base
    [joint_fit_test.step, simple_base.step, simple_base.stl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]
2026-09-03 Derive leader chain from the YAM URDF at 0.75 scale
    The link lengths were each scaled differently (upper arm 0.31x, wrist
    1.34x, shoulder 1.9x) plus a 55 mm lift, so identical joint angles no
    longer put the operator's hand where the follower's gripper is. Joint
    angles map 1:1 only under a uniform scaling.
    Generate JOINTS and JOINT_LIMITS_DEG from yam.urdf via FK at a cardinal
    build pose, times one LEADER_SCALE. Printed stops are now the follower's
    own limits; only J1 (pot travel) and J3 (printed forearm) fall short.
    Packaging follows: J1's socket faces down onto a column pedestal, J5's
    faces up so link 5 can reach J6 from the sector its moving link cannot
    sweep, and link 6 clears J6's sens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
    [joint_fit_test.step, simple_base.step, simple_base.stl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]
2026-09-03 Drop the leader to 0.68 scale, the measured collision floor
    The previous commit's 0.75 was not a floor, and the README saying so was
    wrong. Running the collision suite down the scale: 0.67 passes, 0.66 puts
    the folded forearm into the base plate. Ship 0.68, one step of margin
    over a real collision, taking the arm from 347 to 321 mm of reach.
    Record the search in simple_cad/README.md, including that link 5 fails
    the valid-solid check at 0.70 and 0.74 for a near-tangency reason and how
    to route around it if the scale changes again.
    Also correct the host-mapping section: the stops are asymmetric now, so a
    centred pot is not the middle of the follower's range on the shoulder and
    elbow. Give th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
    [joint_fit_test.step, simple_base.step, simple_base.stl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]
2026-09-03 Rewrite both READMEs for a first-time reader
    Cut the design history: comparisons to the shape this replaced, the old
    cart, the search narrative, and the tests described as rejecting earlier
    obstructions. A reader building this arm has no idea what came before.
    Main README drops from 3634 to 2858 words with every fact, step, and
    warning kept.
    Claude-Session: https://claude.ai/code/session_01JaBVzCqyX4wu4fFjDuTpAW
